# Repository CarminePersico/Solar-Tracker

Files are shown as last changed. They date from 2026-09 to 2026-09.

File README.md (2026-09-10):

# Dual-Axis Solar Tracker (STM32 Bare-Metal)




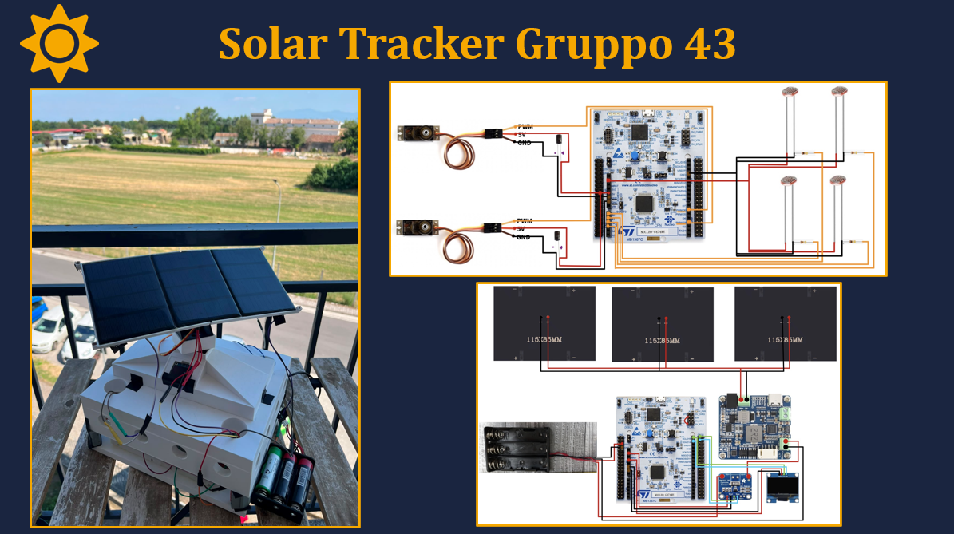
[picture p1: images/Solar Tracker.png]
Schematic

An automated, self-sufficient dual-axis solar tracker engineered from scratch using **Bare-Metal C** on the **STM32G474RE** microcontroller. 

This repository was developed as an exam project for the **Computer Architecture and Design** course. It demonstrates low-level hardware control (memory-mapped registers), advanced interrupt handling, and autonomous power management without relying on heavy abstraction layers like HAL.

---

##  Table of Contents
1. [System Overview](#-system-overview)
2. [Bill of Materials (Components)](#-bill-of-materials-components)
3. [3D Printing Designs](#-3d-printing-designs)
4. [Software & Peripherals](#-software--peripherals)
5. [Operating Logic](#-operating-logic)
6. [Power Management & Telemetry](#-power-management--telemetry)
7. [Getting Started](#-getting-started)

---

##  System Overview
The goal of this project is to create a fully autonomous solar energy harvesting system. The tracker uses light-dependent resistors (LDRs) to detect the position of the sun and orients the solar panel using two servos (Pan and Tilt) to maximize light incidence. 

To ensure the system is completely self-sufficient:
* The panel charges a **Li-Ion battery** through an **MPPT** (Maximum Power Point Tracking) module.
* The MCU spends most of its time in a deep **Stop Mode**, waking up periodically via an internal **RTC Timer** to adjust the panel and measure energy statistics.
* An **INA219** sensor continuously monitors current and voltage, proving the energetic advantage of the tracking movement in real-time.

---

##  Bill of Materials (Components)
Below is the complete list of hardware components used to build the solar tracker:

* **Microcontroller:** STMicroelectronics NUCLEO-G474RE (ARM Cortex-M4)
* **Solar Panel:** 12V, 1.5W peak power output rigid panel
* **Light Sensors:** 4x LDRs (Light Dependent Resistors) paired with voltage divider resistors
* **Actuators:** 2x MG90S Micro Servomotors (for Pan and Tilt axes)
* **Power Sensor:** INA219 I2C DC current and voltage sensor module
* **Power Management:** MPPT (Maximum Power Point Tracking) charging module
* **Battery:** 1x 18650 Li-Ion Cell (3.7V)
* **Protection:** Battery Management System (BMS) for under/over-voltage protection
* **Display:** 0.96" OLED SSD1306 (128x64) communicating via I2C
* **Miscellaneous:** Breadboards, jumper wires, and 10k/1k resistors for the sensor dividers

---

##  3D Printing Designs
All the structural components of the solar tracker were custom-designed and 3D printed. You can find all the `.stl` and CAD project files in the dedicated 3D printing folder of this repository.

The 3D printed assembly includes:
* The main base and electronics housing.
* The Pan and Tilt articulation mechanisms designed to house the MG90S servos.
* The support frame holding the solar panel and perfectly aligning the 4 corner LDRs on the same plane.

---

##  Software & Peripherals
The entire software stack is written in pure bare-metal C (`mainPROG.c`), directly manipulating MCU registers to configure clocks, GPIOs, and interrupts.

* **ADC1 & ADC2**: Reads the analog values from the 4 LDRs (12-bit resolution, 0-4095).
* **TIM2 (PWM)**: Operates at 50Hz to generate the precise control signals for the Pan and Tilt servos.
* **I2C1**: A shared bus controlling both the INA219 power sensor and the SSD1306 OLED display. *Note: The OLED driver was custom-written from scratch to minimize memory footprint, avoiding heavy external libraries.*
* **USART2**: Asynchronous serial communication (115200 baud) for detailed PC telemetry logging.
* **RTC (Real-Time Clock)**: Triggers periodic Wakeup Timer interrupts to pull the MCU out of deep sleep.
* **EXTI / NVIC**: Manages hardware interrupts (RTC Wakeup, User Button B1).

---

##  Operating Logic

### 1. Light Tracking Algorithm
The system uses a comparative differential algorithm. The four LDRs are paired (Top vs. Bottom, Left vs. Right). 
If the difference between opposite pairs exceeds a defined `TOLERANCE`, the system adjusts the corresponding servo. To prevent mechanical strain and violent oscillations (pendulum effect), the servos move in **micro-steps** (~1° at a time) with brief stabilization pauses.

### 2. Zenith Saturation / "Sniper Mode"
When the sun is directly overhead, all LDRs saturate to their maximum values, making differences virtually indistinguishable (noise). The software detects this edge case and ceases unnecessary calculations and movements to save power and prevent fine-limit collisions.

### 3. Operating Phases
The lifecycle is divided into two programmable phases, managed by the RTC:
* **Demo Phase (First 20 Cycles):** The MCU wakes up every **2 seconds**, performs tracking, logs telemetry to the OLED/PC, and goes back to sleep. Ideal for presentations.
* **Industrial Phase:** The MCU shifts to a **15-minute** sleep interval. This creates a highly positive net energy balance, as the brief ~1-second active tracking cost is easily offset by the power generated during the long sleep window.

---

##  Power Management & Telemetry

### Mitigating Voltage Sag
A naive direct connection between the solar panel, servos, and MCU would result in system resets. When the MG90S servos spike in current demand, the bus voltage sags. The inclusion of the **MPPT module** and **BMS** isolates the logic circuit from the actuators, ensuring the STM32 remains stable even during peak mechanical load.

### Telemetry Output
Upon every wake-up cycle, the OLED and USART output the following statistics:
* **Battery State:** Voltage (mV) and estimated Charge Percentage (%).
* **Current & Power:** Real-time generation (mA and mW).
* **Sensor Values:** Raw analog values of the 4 LDRs.
* **Actuator State:** Current Pan and Tilt angles.

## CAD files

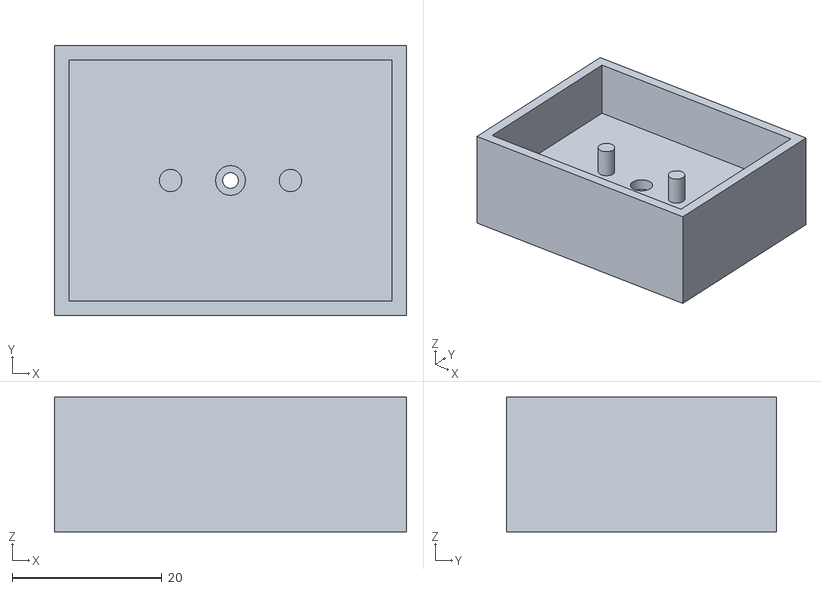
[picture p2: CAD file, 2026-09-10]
3D print files/3.stl
47.0 x 36.0 x 18.0

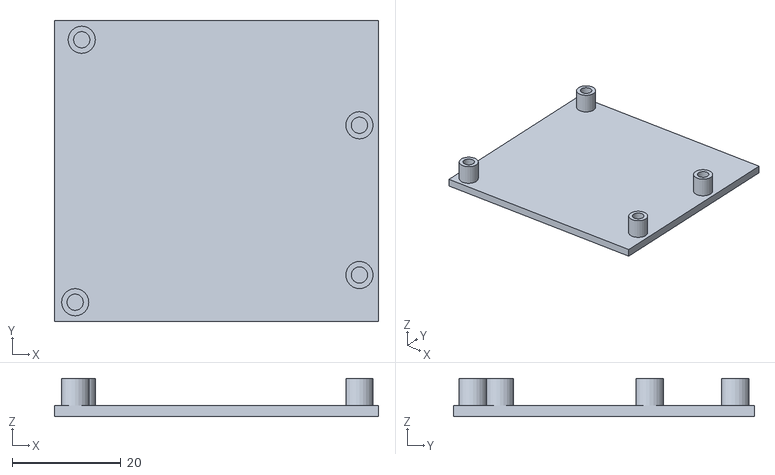
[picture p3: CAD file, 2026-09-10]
3D print files/9.stl
59.5 x 55.2 x 7.00

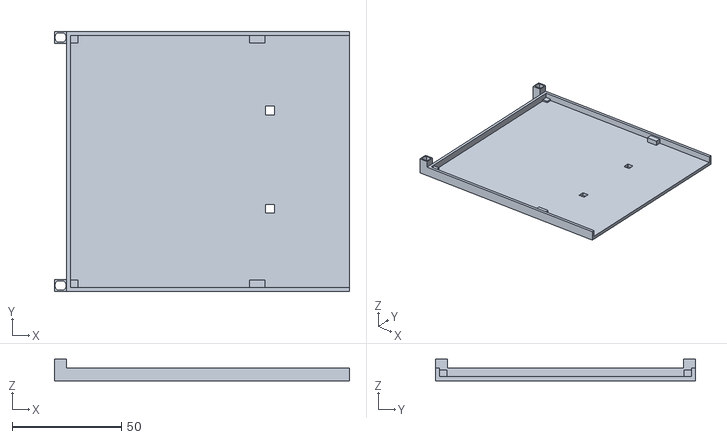
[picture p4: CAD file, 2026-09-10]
3D print files/7.stl
135.0 x 119.0 x 10.00

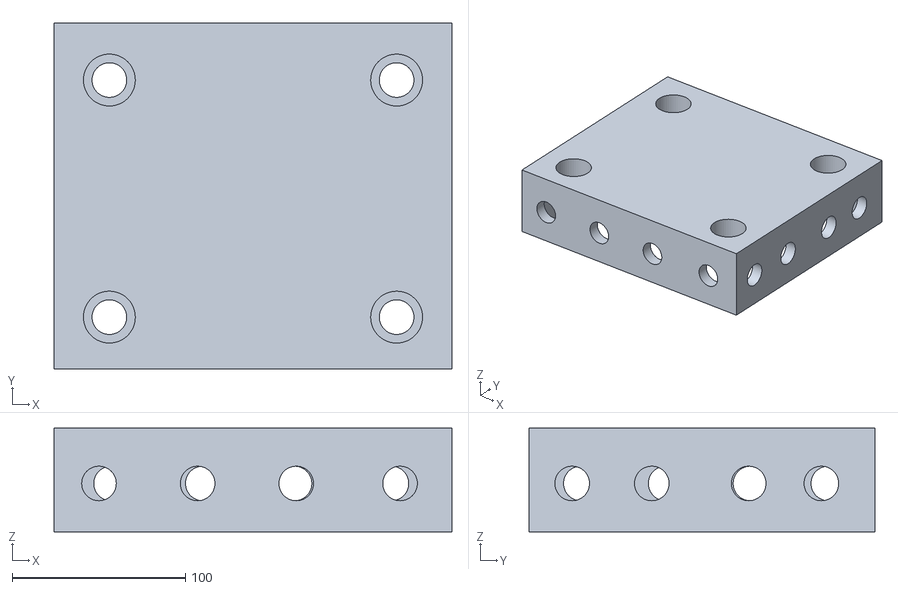
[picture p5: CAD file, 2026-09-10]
3D print files/BASE CON BUCHI VENTILAZIONE.stl
230.0 x 200.0 x 60.0

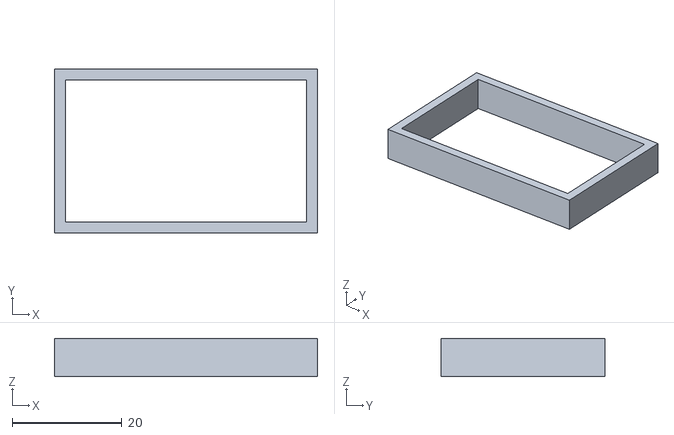
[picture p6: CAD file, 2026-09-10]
3D print files/2.stl
48.0 x 30.0 x 7.00

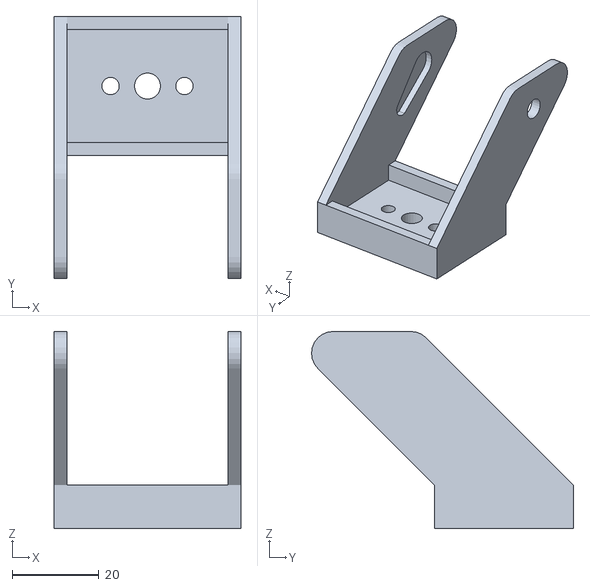
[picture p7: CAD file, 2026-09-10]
3D print files/4.stl
43.0 x 60.3 x 45.4

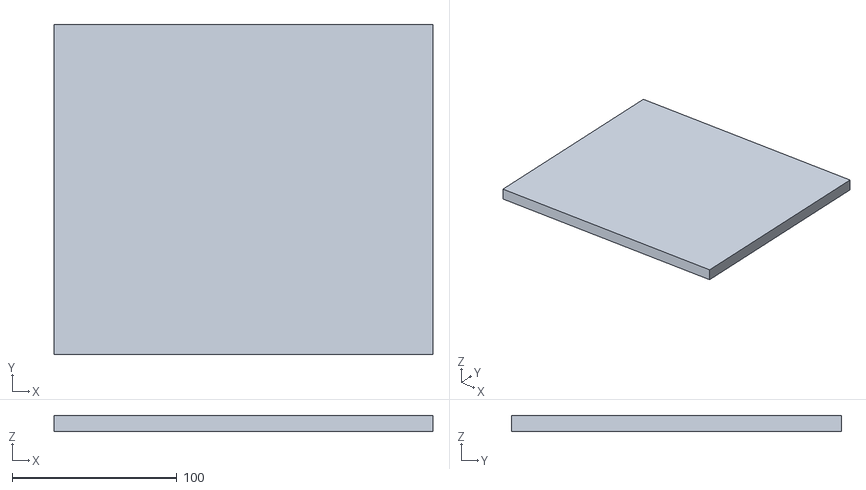
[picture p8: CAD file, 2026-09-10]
3D print files/PIATTO BASE.stl
230.0 x 200.0 x 10.0

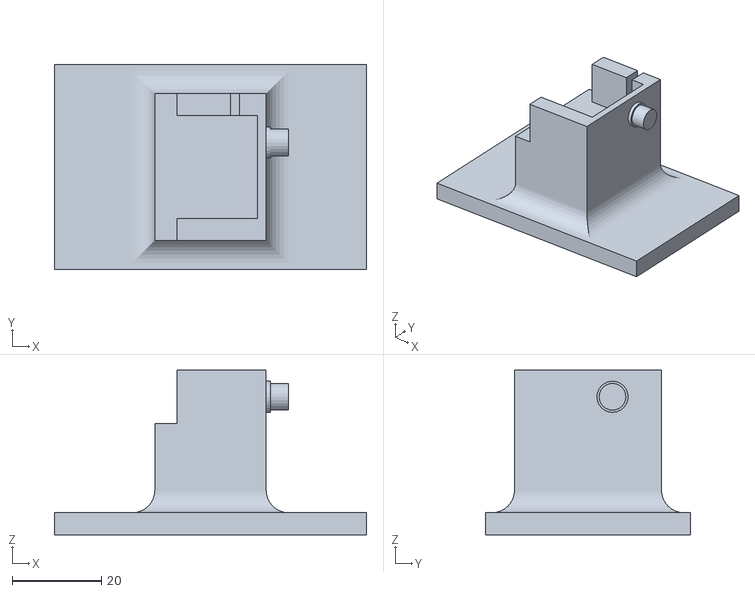
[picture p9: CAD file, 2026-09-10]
3D print files/5.stl
70.0 x 46.0 x 37.0

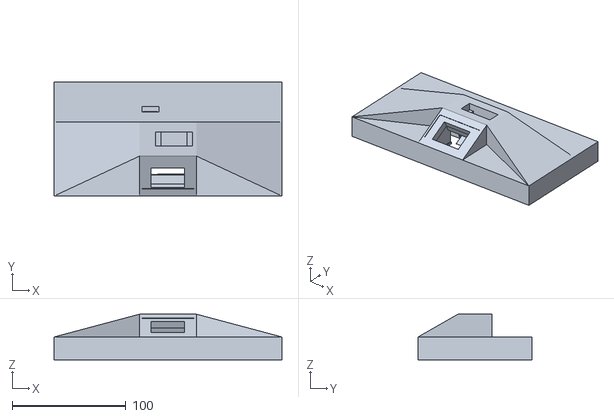
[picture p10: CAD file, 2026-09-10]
3D print files/PRIAMIDE FINALE .stl
200.0 x 100.0 x 40.0

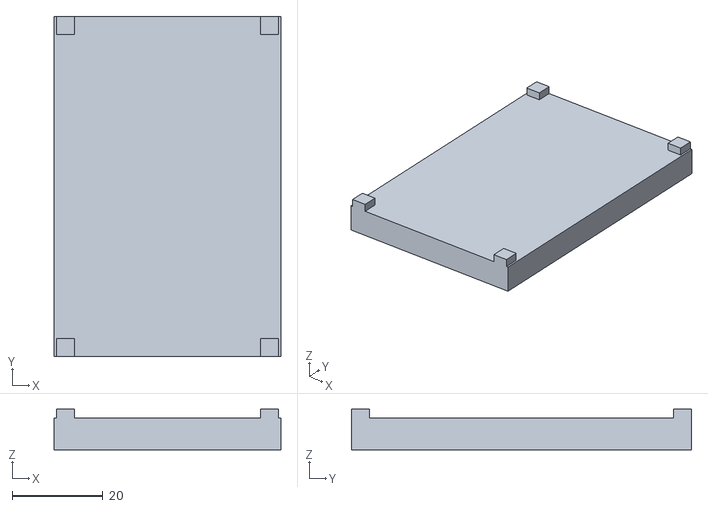
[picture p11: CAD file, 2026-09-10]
3D print files/6.stl
50.0 x 75.0 x 9.00

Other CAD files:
3D print files/8.stl

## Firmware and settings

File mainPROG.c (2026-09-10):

/*
 * Solar Tracker Dual-Axis + INA219 + OLED + RTC Wakeup Timer
 * NUCLEO-G474RE (STM32G474RETx) -- HSI 16 MHz, bare-metal C puro
 */

#include <stdint.h>
#include <stdlib.h> /* Aggiunto per abs() del tracking */

/* ================================================================
   BASE ADDRESSES
   ================================================================ */
#define RCC_BASE    0x40021000UL
#define GPIOA_BASE  0x48000000UL
#define GPIOB_BASE  0x48000400UL
#define GPIOC_BASE  0x48000800UL
#define TIM2_BASE   0x40000000UL
#define ADC1_BASE   0x50000000UL
#define ADC2_BASE   0x50000100UL
#define ADC12_BASE  0x50000300UL
#define USART2_BASE 0x40004400UL
#define I2C1_BASE   0x40005400UL
#define EXTI_BASE   0x40010400UL
#define PWR_BASE    0x40007000UL
#define RTC_BASE    0x40002800UL

/* RCC */
#define RCC_AHB2ENR  (*(volatile uint32_t*)(RCC_BASE + 0x4C))
#define RCC_APB2ENR  (*(volatile uint32_t*)(RCC_BASE + 0x60))
#define RCC_APB1ENR1 (*(volatile uint32_t*)(RCC_BASE + 0x58))
#define RCC_BDCR     (*(volatile uint32_t*)(RCC_BASE + 0x90))
#define RCC_CSR      (*(volatile uint32_t*)(RCC_BASE + 0x94))

/* GPIO */
#define GPIOA_MODER  (*(volatile uint32_t*)(GPIOA_BASE + 0x00))
#define GPIOA_AFRL   (*(volatile uint32_t*)(GPIOA_BASE + 0x20))
#define GPIOA_ODR    (*(volatile uint32_t*)(GPIOA_BASE + 0x14))

#define GPIOB_MODER  (*(volatile uint32_t*)(GPIOB_BASE + 0x00))
#define GPIOB_OTYPER (*(volatile uint32_t*)(GPIOB_BASE + 0x04))
#define GPIOB_PUPDR  (*(volatile uint32_t*)(GPIOB_BASE + 0x0C))
#define GPIOB_AFRL   (*(volatile uint32_t*)(GPIOB_BASE + 0x20))
#define GPIOB_AFRH   (*(volatile uint32_t*)(GPIOB_BASE + 0x24))

#define GPIOC_MODER  (*(volatile uint32_t*)(GPIOC_BASE + 0x00))

/* TIM2 */
#define TIM2_CR1   (*(volatile uint32_t*)(TIM2_BASE + 0x00))
#define TIM2_EGR   (*(volatile uint32_t*)(TIM2_BASE + 0x14))
#define TIM2_CCMR1 (*(volatile uint32_t*)(TIM2_BASE + 0x18))
#define TIM2_CCMR2 (*(volatile uint32_t*)(TIM2_BASE + 0x1C))
#define TIM2_CCER  (*(volatile uint32_t*)(TIM2_BASE + 0x20))
#define TIM2_PSC   (*(volatile uint32_t*)(TIM2_BASE + 0x28))
#define TIM2_ARR   (*(volatile uint32_t*)(TIM2_BASE + 0x2C))
#define TIM2_CCR2  (*(volatile uint32_t*)(TIM2_BASE + 0x38))
#define TIM2_CCR3  (*(volatile uint32_t*)(TIM2_BASE + 0x3C))
#define TIM2_DIER  (*(volatile uint32_t*)(TIM2_BASE + 0x0C))
#define TIM2_SR    (*(volatile uint32_t*)(TIM2_BASE + 0x10))

/* ADC */
#define ADC12_CCR  (*(volatile uint32_t*)(ADC12_BASE + 0x08))
#define ADC1_ISR   (*(volatile uint32_t*)(ADC1_BASE  + 0x00))
#define ADC1_CR    (*(volatile uint32_t*)(ADC1_BASE  + 0x08))
#define ADC1_SMPR1 (*(volatile uint32_t*)(ADC1_BASE  + 0x14))
#define ADC1_SMPR2 (*(volatile uint32_t*)(ADC1_BASE  + 0x18))
#define ADC1_SQR1  (*(volatile uint32_t*)(ADC1_BASE  + 0x30))
#define ADC1_DR    (*(volatile uint32_t*)(ADC1_BASE  + 0x40))
#define ADC2_ISR   (*(volatile uint32_t*)(ADC2_BASE  + 0x00))
#define ADC2_CR    (*(volatile uint32_t*)(ADC2_BASE  + 0x08))
#define ADC2_SMPR2 (*(volatile uint32_t*)(ADC2_BASE  + 0x18))
#define ADC2_SQR1  (*(volatile uint32_t*)(ADC2_BASE  + 0x30))
#define ADC2_DR    (*(volatile uint32_t*)(ADC2_BASE  + 0x40))

/* USART2 */
#define USART2_CR1 (*(volatile uint32_t*)(USART2_BASE + 0x00))
#define USART2_BRR (*(volatile uint32_t*)(USART2_BASE + 0x0C))
#define USART2_ISR (*(volatile uint32_t*)(USART2_BASE + 0x1C))
#define USART2_TDR (*(volatile uint32_t*)(USART2_BASE + 0x28))

/* I2C1 */
#define I2C1_CR1     (*(volatile uint32_t*)(I2C1_BASE + 0x00))
#define I2C1_CR2     (*(volatile uint32_t*)(I2C1_BASE + 0x04))
#define I2C1_TIMINGR (*(volatile uint32_t*)(I2C1_BASE + 0x10))
#define I2C1_ISR     (*(volatile uint32_t*)(I2C1_BASE + 0x18))
#define I2C1_ICR     (*(volatile uint32_t*)(I2C1_BASE + 0x1C))
#define I2C1_RXDR    (*(volatile uint32_t*)(I2C1_BASE + 0x24))
#define I2C1_TXDR    (*(volatile uint32_t*)(I2C1_BASE + 0x28))

#define I2C_ISR_TXIS   (1u << 1)
#define I2C_ISR_RXNE   (1u << 2)
#define I2C_ISR_TC     (1u << 6)
#define I2C_ISR_BUSY   (1u << 15)
#define I2C_ICR_STOPCF (1u << 5)
#define I2C_TIMEOUT    50000u

/* EXTI */
#define EXTI_RTSR1   (*(volatile uint32_t*)(EXTI_BASE + 0x00))
#define EXTI_FTSR1   (*(volatile uint32_t*)(EXTI_BASE + 0x04))
#define EXTI_SWIER1  (*(volatile uint32_t*)(EXTI_BASE + 0x08))
#define EXTI_RPR1    (*(volatile uint32_t*)(EXTI_BASE + 0x0C))
#define EXTI_FPR1    (*(volatile uint32_t*)(EXTI_BASE + 0x10))
#define EXTI_EXTICR4 (*(volatile uint32_t*)(EXTI_BASE + 0x6C))
#define EXTI_IMR1    (*(volatile uint32_t*)(EXTI_BASE + 0x80))
#define EXTI_EMR1    (*(volatile uint32_t*)(0x40010484u))

/* NVIC */
#define NVIC_ISER0 (*(volatile uint32_t*)0xE000E100)
#define NVIC_ISER1 (*(volatile uint32_t*)0xE000E104)
#define NVIC_ICPR0 (*(volatile uint32_t*)0xE000E280)

/* PWR / SCB */
#define PWR_CR1 (*(volatile uint32_t*)(PWR_BASE + 0x00))
#define SCB_SCR (*(volatile uint32_t*)0xE000ED10)

/* RTC */
#define RTC_TR   (*(volatile uint32_t*)(RTC_BASE + 0x00))
#define RTC_DR   (*(volatile uint32_t*)(RTC_BASE + 0x04))
#define RTC_ICSR (*(volatile uint32_t*)(RTC_BASE + 0x0C))
#define RTC_PRER (*(volatile uint32_t*)(RTC_BASE + 0x10))
#define RTC_WUTR (*(volatile uint32_t*)(RTC_BASE + 0x14))
#define RTC_CR   (*(volatile uint32_t*)(RTC_BASE + 0x18))
#define RTC_WPR  (*(volatile uint32_t*)(RTC_BASE + 0x24))
#define RTC_SR   (*(volatile uint32_t*)(RTC_BASE + 0x50))
#define RTC_SCR  (*(volatile uint32_t*)(RTC_BASE + 0x5C))

#define RTC_CR_WUTE  (1u << 10)
#define RTC_CR_WUTIE (1u << 14)
#define RTC_ICSR_WUTWF (1u << 2)
#define RTC_ICSR_INITF (1u << 6)
#define RTC_ICSR_INIT  (1u << 7)
#define RTC_SCR_CWUTF  (1u << 2)

/* ================================================================
   INA219 (Aggiornato)
   ================================================================ */
#define INA219_ADDR    0x40u
#define INA219_REG_CFG 0x00u
#define INA219_REG_SHV 0x01u
#define INA219_REG_BUS 0x02u
#define INA219_REG_CUR 0x04u
#define INA219_REG_CAL 0x05u
#define INA219_CFG_VAL 0x399Fu
#define INA219_CAL_VAL 4096u /* LSB = 0.1 mA */

/* ================================================================
   TRACKING (Aggiornato dal Codice 1)
   ================================================================ */
#define TOLERANCE 350
#define STEP      11
#define PWM_MIN   611
#define PWM_MAX   2500

/* ================================================================
   FASI OPERATIVE
   ================================================================ */
#define PHASE_DEMO        0u
#define PHASE_INDUSTRIAL  1u
#define DEMO_CYCLES       20u
#define WAKEUP_DEMO_S     2u
#define WAKEUP_IND_S      900u

/* ================================================================
   VARIABILI GLOBALI
   ================================================================ */
volatile uint8_t rtc_wakeup_flag = 0;
volatile uint8_t b1_flag         = 0;

/* Posizioni iniziali */
static int32_t angle_pan  = 1633;
static int32_t angle_tilt = 1833;

static uint8_t  current_phase    = PHASE_DEMO;
static uint32_t demo_cycle_count = 0;
static uint32_t total_cycles     = 0;

static int32_t oled_vbat = 0;
static int32_t oled_curr = 0;
static int32_t oled_pwr  = 0;
static uint8_t oled_online = 0;

/* ================================================================
   UTILITY
   ================================================================ */
static void delay_ms(volatile uint32_t ms) {
    while (ms--) { volatile uint32_t i = 3400; while (i--); }
}

static void uart_putc(char c) {
    while (!(USART2_ISR & (1u << 7)));
    USART2_TDR = (uint32_t)c;
}
static void uart_puts(const char *s) { while (*s) uart_putc(*s++); }
static void uart_puti(int32_t n) {
    char buf[12]; int i = 0;
    if (n < 0) { uart_putc('-'); n = -n; }
    if (n == 0) { uart_putc('0'); return; }
    while (n > 0) { buf[i++] = '0' + (char)(n % 10); n /= 10; }
    while (i--) uart_putc(buf[i]);
}

static void uart_flush(void) {
    while (!(USART2_ISR & (1u << 6)));
    delay_ms(2);
}

/* ================================================================
   ADC
   ================================================================ */
static void adc1_init(void) {
    ADC1_CR  = 0;
    ADC1_CR  = (1u << 28);
    delay_ms(5);
    ADC1_CR |= (1u << 31);
    while (ADC1_CR & (1u << 31));
    ADC1_ISR |= (1u << 0);
    ADC1_CR  |= (1u << 0);
    while (!(ADC1_ISR & (1u << 0)));
    ADC1_SMPR1 = (5u << 6) | (5u << 21);
    ADC1_SMPR2 = (5u << 15);
}

static void adc2_init(void) {
    ADC2_CR  = 0;
    ADC2_CR  = (1u << 28);
    delay_ms(5);
    ADC2_CR |= (1u << 31);
    while (ADC2_CR & (1u << 31));
    ADC2_ISR |= (1u << 0);
    ADC2_CR  |= (1u << 0);
    while (!(ADC2_ISR & (1u << 0)));
    ADC2_SMPR2 = (5u << 21);
}

static void adc_wakeup_restore(void) {
    if (!(ADC1_CR & (1u << 0))) { adc1_init(); }
    if (!(ADC2_CR & (1u << 0))) { adc2_init(); }
}

static uint32_t adc1_read(uint32_t ch) {
    ADC1_SQR1 = (ch << 6);
    ADC1_CR  |= (1u << 2);
    while (!(ADC1_ISR & (1u << 2)));
    uint32_t v = ADC1_DR;
    ADC1_ISR  = (1u << 2);
    return v;
}
static uint32_t adc2_read(uint32_t ch) {
    ADC2_SQR1 = (ch << 6);
    ADC2_CR  |= (1u << 2);
    while (!(ADC2_ISR & (1u << 2)));
    uint32_t v = ADC2_DR;
    ADC2_ISR  = (1u << 2);
    return v;
}

/* ================================================================
   I2C1 / INA219 (Aggiornato per supportare i decimali della corrente)
   ================================================================ */
static int i2c_write_reg(uint8_t addr7, uint8_t reg, uint16_t val) {
    volatile uint32_t t = I2C_TIMEOUT;
    while ((I2C1_ISR & I2C_ISR_BUSY) && --t); if (!t) return -1;
    I2C1_CR2 = ((uint32_t)(addr7<<1) & 0x3FFu) | (3u<<16) | (1u<<25) | (1u<<13);
    t = I2C_TIMEOUT;
    while (!(I2C1_ISR & I2C_ISR_TXIS) && --t); if (!t) return -2;
    I2C1_TXDR = reg;
    t = I2C_TIMEOUT;
    while (!(I2C1_ISR & I2C_ISR_TXIS) && --t); if (!t) return -3;
    I2C1_TXDR = (val >> 8) & 0xFFu;
    t = I2C_TIMEOUT;
    while (!(I2C1_ISR & I2C_ISR_TXIS) && --t); if (!t) return -4;
    I2C1_TXDR = val & 0xFFu;
    t = I2C_TIMEOUT;
    while (!(I2C1_ISR & (1u<<5)) && --t);
    I2C1_ICR = I2C_ICR_STOPCF;
    return 0;
}

static int i2c_read_reg16(uint8_t addr7, uint8_t reg, int16_t *out) {
    volatile uint32_t t = I2C_TIMEOUT;
    while ((I2C1_ISR & I2C_ISR_BUSY) && --t); if (!t) return -1;
    I2C1_CR2 = ((uint32_t)(addr7<<1) & 0x3FFu) | (1u<<16) | (1u<<13);
    t = I2C_TIMEOUT;
    while (!(I2C1_ISR & I2C_ISR_TXIS) && --t); if (!t) return -2;
    I2C1_TXDR = reg;
    t = I2C_TIMEOUT;
    while (!(I2C1_ISR & I2C_ISR_TC) && --t); if (!t) return -3;
    I2C1_CR2 = ((uint32_t)(addr7<<1) & 0x3FFu) | (1u<<10) | (2u<<16) | (1u<<25) | (1u<<13);
    t = I2C_TIMEOUT;
    while (!(I2C1_ISR & I2C_ISR_RXNE) && --t); if (!t) return -4;
    uint8_t msb = (uint8_t)I2C1_RXDR;
    t = I2C_TIMEOUT;
    while (!(I2C1_ISR & I2C_ISR_RXNE) && --t); if (!t) return -5;
    uint8_t lsb = (uint8_t)I2C1_RXDR;
    t = I2C_TIMEOUT;
    while (!(I2C1_ISR & (1u<<5)) && --t);
    I2C1_ICR = I2C_ICR_STOPCF;
    *out = (int16_t)((uint16_t)(msb<<8) | lsb);
    return 0;
}

static void ina219_print(void) {
    int16_t sv_raw, bv_raw, cv_raw;
    int r = 0;

    r |= i2c_read_reg16(INA219_ADDR, INA219_REG_SHV, &sv_raw);
    r |= i2c_read_reg16(INA219_ADDR, INA219_REG_BUS, &bv_raw);
    r |= i2c_read_reg16(INA219_ADDR, INA219_REG_CUR, &cv_raw);

    if (r != 0) {
        uart_puts(" | INA_ERR");
        oled_vbat=0; oled_curr=0; oled_pwr=0;
        return;
    }

    int32_t millivolt = (bv_raw >> 3) * 4;
    int32_t current_decima = (int32_t)cv_raw;
    int32_t milliwatt = (millivolt * current_decima) / 10000;

    // Calcolo Percentuale Batteria Li-Ion (Range 3200mV - 4200mV)
    /* Calcolo Percentuale (Range 3300mV - 4100mV) */
        int32_t pct = ((millivolt - 3300) * 100) / 800;
        if (pct > 100) pct = 100;
        if (pct < 0) pct = 0;

    oled_vbat = millivolt;
    oled_curr = current_decima / 10;
    oled_pwr  = milliwatt;

    // Nuova stampa UART con percentuale
    uart_puts(" | BATT: "); uart_puti(millivolt);
    uart_puts(" mV ("); uart_puti(pct); uart_puts("%) | CURR: ");

    int32_t c_temp = current_decima;
    if (c_temp < 0) { uart_putc('-'); c_temp = -c_temp; }
    uart_puti(c_temp / 10); uart_putc('.'); uart_puti(c_temp % 10);
    uart_puts(" mA | PWR: "); uart_puti(milliwatt); uart_puts(" mW");
}

/* ================================================================
   OLED SSD1306 (I2C1)
   ================================================================ */
#define OLED_ADDR 0x3C

static int i2c_write_oled(uint8_t ctrl, uint8_t data) {
    volatile uint32_t t = I2C_TIMEOUT;
    while ((I2C1_ISR & I2C_ISR_BUSY) && --t);
    if (!t) return -1;
    I2C1_CR2 = ((uint32_t)(OLED_ADDR<<1) & 0x3FFu) | (2u<<16) | (1u<<25) | (1u<<13);
    t = I2C_TIMEOUT;
    while (!(I2C1_ISR & I2C_ISR_TXIS) && --t);
    if (!t) return -2;
    I2C1_TXDR = ctrl;
    t = I2C_TIMEOUT;
    while (!(I2C1_ISR & I2C_ISR_TXIS) && --t);
    if (!t) return -3;
    I2C1_TXDR = data;
    t = I2C_TIMEOUT;
    while (!(I2C1_ISR & (1u<<5)) && --t);
    I2C1_ICR = I2C_ICR_STOPCF;
    return 0;
}

static int oled_cmd(uint8_t cmd)   { return i2c_write_oled(0x00, cmd); }
static int oled_data(uint8_t data) { return i2c_write_oled(0x40, data); }

static void oled_wake(void)  { oled_cmd(0xAF); }
static void oled_sleep(void) { oled_cmd(0xAE); }

/* ================================================================
   SERVO
   ================================================================ */
static void servo_enable(void) {
    TIM2_CCR2 = (uint32_t)angle_pan;
    TIM2_CCR3 = (uint32_t)angle_tilt;
    TIM2_EGR  |= (1u << 0);
    TIM2_CR1  |= (1u << 0);
    TIM2_CCER |= (1u << 4) | (1u << 8);
}

static void servo_disable(void) {
    TIM2_CCER &= ~((1u << 4) | (1u << 8));
}

/* ================================================================
   TRACKING (Aggiornato con la logica esatta del Codice 1)
   ================================================================ */
static void do_tracking(void) {
    uint32_t passi = 0;
    uint32_t lt = 0, rt = 0, ld = 0, rd = 0;
    int dvert = 0, dhoriz = 0;

    // Ciclo "Burst": continua a leggere e muovere finché non è allineato
        while (passi < 50) {
            /*

    MAPPATURA DI EMERGENZA */
      // Prima leggiamo tutti i pin grezzi
      uint32_t pin_A4 = adc1_read(7);  // Il vecchio TL
      uint32_t pin_A1 = adc1_read(2);  // Il vecchio TR
      uint32_t pin_A3 = adc1_read(15); // Il vecchio BL
      uint32_t pin_A2 = adc2_read(17); // Il vecchio BR

            // Ora assegniamo forzatamente i valori corretti in base a quello che mi hai detto:
            // Tu hai detto: TL = TR (il pin_A2 risponde al TL)
            lt = pin_A4;

            // Tu hai detto: TR = BR (il pin_A4 risponde al TR)
            rt = pin_A1;

            // Tu hai detto: BL = BL (corretto)
            ld = pin_A3;

            // Tu hai detto: BR = TR (il pin_A1 risponde al BR)
            rd = pin_A2;

            int avt = (lt + rt) / 2;
            int avd = (ld + rd) / 2;
            int avl = (lt + ld) / 2;
            int avr = (rt + rd) / 2;

        dvert  = abs(avt - avd);
        dhoriz = abs(avl - avr);

        uint8_t motore_mosso = 0;

        /* Gestione PAN (SEGNI INVERTITI per inseguire la luce dal lato giusto) */
        if (dhoriz > TOLERANCE) {
            if (avl > avr) {
                /* C'è più LUCE a SINISTRA. Andiamo a Sinistra! (segno -) */
                if (angle_pan - STEP >= PWM_MIN) { angle_pan -= STEP; motore_mosso = 1; }
            } else if (avl < avr) {
                /* C'è più LUCE a DESTRA. Andiamo a Destra! (segno +) */
                if (angle_pan + STEP <= PWM_MAX) { angle_pan += STEP; motore_mosso = 1; }
            }
            TIM2_CCR2 = (uint32_t)angle_pan;
        }

        /* Gestione TILT (SEGNI INVERTITI per coerenza) */
        if (dvert > TOLERANCE) {
            if (avt > avd) {
                /* C'è più LUCE SOPRA. Andiamo in Alto! (segno -) */
                if (angle_tilt - STEP >= PWM_MIN) { angle_tilt -= STEP; motore_mosso = 1; }
            } else if (avt < avd) {
                /* C'è più LUCE SOTTO. Andiamo in Basso! (segno +) */
                if (angle_tilt + STEP <= PWM_MAX) { angle_tilt += STEP; motore_mosso = 1; }
            }
            TIM2_CCR3 = (uint32_t)angle_tilt;
        }

        if (motore_mosso == 0) {
            break;
        }

        delay_ms(20);
        passi++;
    }

    /* Stampe di Debug */
    uart_puts(" | LDR: TL="); uart_puti(lt);
    uart_puts(" TR=");        uart_puti(rt);
    uart_puts(" BL=");        uart_puti(ld);
    uart_puts(" BR=");        uart_puti(rd);

    uart_puts(" | Diff: H="); uart_puti(dhoriz);
    uart_puts(" V=");         uart_puti(dvert);

    uart_puts(" | PASSI=");   uart_puti(passi);
    uart_puts(" | PAN=");     uart_puti(angle_pan);
    uart_puts(" TILT=");      uart_puti(angle_tilt);
}
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
int main(void) {
    *(volatile uint32_t*)0x40021060u |= (1u << 0);
    (*(volatile uint32_t*)0xE0042004) &= ~(5u);

    RCC_CSR |= (1u << 23);

    /* 1. Clock enable */
    RCC_AHB2ENR  |= (1u<<0)|(1u<<1)|(1u<<2)|(1u<<13);
    RCC_APB1ENR1 |= (1u<<0) | (1u<<17) | (1u<<21) | (1u<<28);
    RCC_APB2ENR  |= (1u << 0);

    /* 2. GPIO */
    GPIOA_MODER |= (3u << 2);
    GPIOA_MODER |= (3u << 8);
    GPIOA_MODER &= ~(3u<<4);   GPIOA_MODER |= (2u<<4);
    GPIOA_AFRL  &= ~(0xFu<<8); GPIOA_AFRL  |= (7u<<8);

    GPIOB_MODER |= (3u << 0);
    GPIOB_MODER &= ~(3u<<6);    GPIOB_MODER |= (2u<<6);
    GPIOB_AFRL  &= ~(0xFu<<12); GPIOB_AFRL  |= (1u<<12);
    GPIOB_MODER  &= ~(3u<<16);  GPIOB_MODER  |= (2u<<16);
    GPIOB_OTYPER |=  (1u<<8);
    GPIOB_PUPDR  &= ~(3u<<16);  GPIOB_PUPDR  |= (1u<<16);
    GPIOB_AFRH   &= ~(0xFu<<0); GPIOB_AFRH   |= (4u<<0);
    GPIOB_MODER  &= ~(3u<<18);  GPIOB_MODER  |= (2u<<18);
    GPIOB_OTYPER |=  (1u<<9);
    GPIOB_PUPDR  &= ~(3u<<18);  GPIOB_PUPDR  |= (1u<<18);
    GPIOB_AFRH   &= ~(0xFu<<4); GPIOB_AFRH   |= (4u<<4);
    GPIOB_MODER &= ~(3u<<20);   GPIOB_MODER |= (2u<<20);
    GPIOB_AFRH  &= ~(0xFu<<8);  GPIOB_AFRH  |= (1u<<8);

    GPIOC_MODER |= (3u << 2);

    GPIOA_MODER &= ~(3u << 10);
    GPIOA_MODER |=  (1u << 10);
    GPIOA_ODR   |=  (1u << 5);

    /* 3. USART2 */
    USART2_BRR = 139u;
    USART2_CR1 = (1u<<3) | (1u<<0);

    /* 4. ADC */
    ADC12_CCR &= ~(3u << 16);
    ADC12_CCR |=  (1u << 16);
    adc1_init();
    adc2_init();

    /* 5. TIM2 PWM */
    TIM2_PSC = 15u;
    TIM2_ARR = 19999u;
    TIM2_CCMR1 &= ~(0xFFu << 8); TIM2_CCMR1 |= (0x68u << 8);
    TIM2_CCMR2 &= ~(0xFFu);      TIM2_CCMR2 |= (0x68u);
    TIM2_CCR2 = (uint32_t)angle_pan;
    TIM2_CCR3 = (uint32_t)angle_tilt;
    TIM2_EGR  |= (1u << 0);
    TIM2_CR1  |= (1u << 0);
    TIM2_DIER |= (1u << 0);
    *(volatile uint32_t*)0xE000E100u |= (1u << 28);

    /* 6. I2C1 */
    I2C1_CR1     = 0;
    I2C1_TIMINGR = 0x00303D5Bu;
    I2C1_CR1     = (1u << 0);
    delay_ms(2);

    if (oled_init() == 0) {
        oled_online = 1;
        oled_clear();
        uart_puts("OLED: ONLINE\r\n");
    } else {
        uart_puts("[WARN] OLED assente\r\n");
    }

    /* 7. EXTI B1 */
    EXTI_EXTICR4 &= ~(0xFu << 4); EXTI_EXTICR4 |= (0x2u << 4);
    EXTI_FTSR1   |= (1u << 13);
    EXTI_IMR1    |= (1u << 13);
    NVIC_ISER1    = (1u << 8);

    /* 8. Interrupt globali on */
    __asm volatile ("cpsie i" ::: "memory");

    /* 9. INA219 init */
    uart_puts("\r\n=== Solar Tracker | INA219 | OLED ===\r\n");
    if (i2c_write_reg(INA219_ADDR, INA219_REG_CFG, INA219_CFG_VAL) != 0 ||
        i2c_write_reg(INA219_ADDR, INA219_REG_CAL, INA219_CAL_VAL) != 0) {
        uart_puts("[WARN] INA219 non risponde\r\n");
    } else {
        uart_puts("INA219 OK\r\n");
    }

    /* 11. RTC wakeup timer init */
    rtc_init();
    uart_puts("RTC OK -- Fase DEMO attiva\r\n\r\n");

    /* 12. MAIN LOOP */
    while (1) {
        GPIOA_ODR |=  (1u << 5);
        delay_ms(500);
        GPIOA_ODR &= ~(1u << 5);

        total_cycles++;
        rtc_wakeup_flag = 0;
        b1_flag         = 0;

        uart_puts("[C#"); uart_puti((int32_t)total_cycles);
        if (current_phase == PHASE_DEMO) uart_puts(" DEMO]  ");
        else                              uart_puts(" IND]   ");

        adc_wakeup_restore();

        /* Diamo 5 millisecondi all'ADC per stabilizzare i condensatori dopo il Deep Sleep */
        delay_ms(5);

        // --- 1. SVEGLIA MOTORI E FAI UN PASSO ---
        servo_enable();
        do_tracking(); // Fa 1 singolo passo come da Codice 1

        // --- 2. ASPETTA E LEGGI ENERGIA ---
        delay_ms(300);
        ina219_print();
        uart_puts("\r\n");

        if (current_phase == PHASE_DEMO) {
            demo_cycle_count++;
            if (demo_cycle_count >= DEMO_CYCLES) {
                current_phase = PHASE_INDUSTRIAL;
                rtc_set_wakeup_period(WAKEUP_IND_S);
            }
        }

        // --- 3. STAMPA SU SCHERMO ---
        oled_wake();

        /* Calcola i gradi con la formula del Codice 1 */
        int32_t pan_deg  = ((angle_pan - 500) * 180) / 2000;
        int32_t tilt_deg = ((angle_tilt - 500) * 180) / 2000;

        oled_print_telemetry(oled_vbat, oled_curr, oled_pwr, pan_deg, tilt_deg);
        delay_ms(4000);
        oled_sleep();

        // --- 4. SPEGNI E DORMI ---
        uart_puts("  >> Sleep...\r\n");
        servo_disable();

        TIM2_CR1  |= (1u << 0);
        TIM2_DIER |= (1u << 0);
        *(volatile uint32_t*)0xE000E100u |= (1u << 28);

        while (!(RTC_SR & (1u << 2))) {
            __asm volatile ("wfi" ::: "memory");
        }

        RTC_WPR = 0xCAu; RTC_WPR = 0x53u;
        RTC_CR  &= ~RTC_CR_WUTE;
        volatile uint32_t t = 100000u;
        while (!(RTC_ICSR & RTC_ICSR_WUTWF) && --t);
        RTC_SCR  = RTC_SCR_CWUTF;
        RTC_CR  |=  RTC_CR_WUTE;
        RTC_WPR  = 0xFFu;

        GPIOA_ODR |= (1u << 5);
        uart_puts("  << Wake!\r\n");
    }
}
